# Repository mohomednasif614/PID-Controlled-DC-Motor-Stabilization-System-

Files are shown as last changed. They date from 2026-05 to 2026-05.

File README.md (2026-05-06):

### PID-Controlled-DC-Motor-Stabilization-System

This repository contains the hardware design and software implementation for a closed-loop motor speed control system. Developed as a group assignment for the Control System Engineering (IE3034) module at SLIIT, the project demonstrates how PID control theory is applied to stabilize a physical DC motor under varying loads and setpoints.

Key Features

Hardware: Integrated a Raspberry Pi 4 with a TB6612FNG motor driver and a 6V N20 geared DC motor.  

Custom PCB: Designed in EasyEDA with high-current trace widths (1mm), power filtering capacitors, and overcurrent protection via PTF-15 fuses.  

PID Implementation: A Python-based controller utilizing the pigpio library for hardware-level timing accuracy.  

Signal Conditioning: Features a 3-point moving average filter to mitigate encoder quantization noise and anti-windup logic to prevent integrator saturation.  

Performance: Achieved a settling time of 1.82 seconds with <1% overshoot and 0.0% steady-state error.

### EasyEDA Schematic
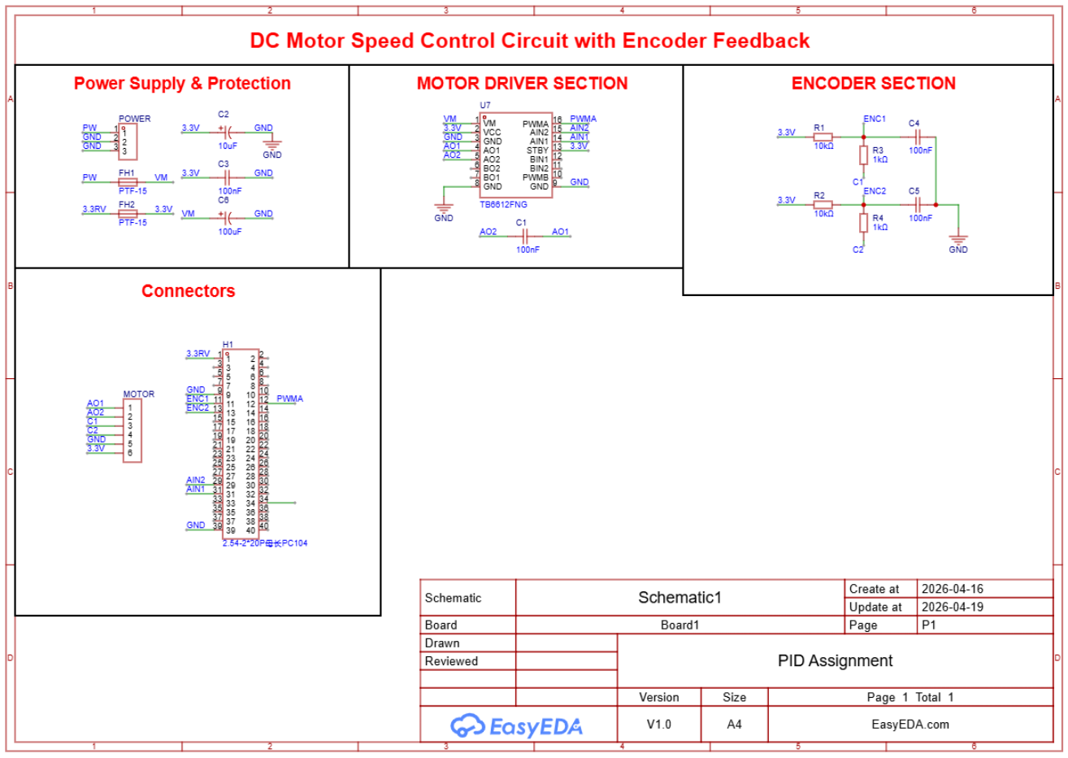
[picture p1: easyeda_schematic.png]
EasyEDA Schematic


### PCB Design
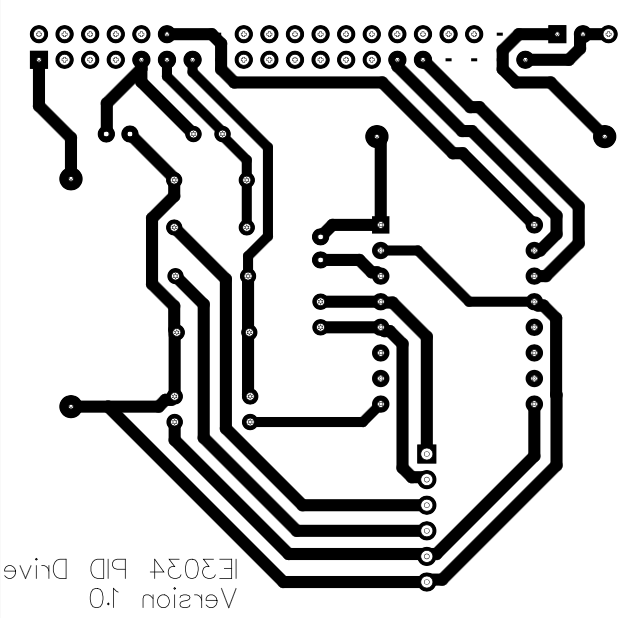
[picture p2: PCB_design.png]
PCB Design


### Circuit
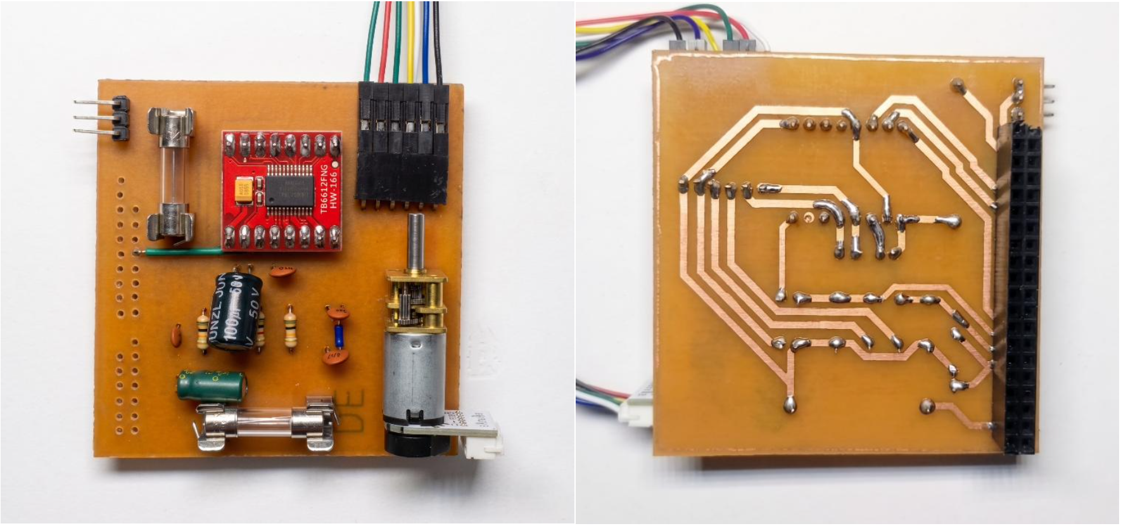
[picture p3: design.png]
Circuit


### Tools Used

Simulation: Proteus 8 Professional
PCB Design: EasyEDA
Documentation: Microsoft Word

### Contact

GitHub: @mohomednasif614

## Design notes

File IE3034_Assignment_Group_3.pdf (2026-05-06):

1 | P a g e

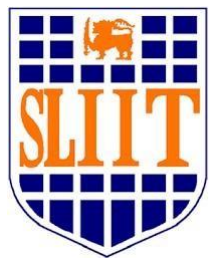
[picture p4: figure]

## BSc (Hons) in Computer Systems Engineering

## IE3034 - Control System Engineering

## Group Assignment

## Design and Performance Analysis of a PID-Controlled DC Motor Stabilization System using Raspberry Pi

Group Members

IT23690370 – W A E Y Perera

IT23736900 – M Nasif

IT23749566 – K M T P Kulasinha

IT23619494 – L K C M Perera

IT23669444 – K V A D C S Perera

Table of Contents

### 1. Introduction

This project focuses on the design, implementation, and performance analysis of a PID-controlled DC motor stabilization system using a Raspberry Pi. The main purpose of the project is to control the speed of a 6V N20 DC motor accurately and make the motor reach a required target speed within a short time while maintaining stability.
In many real-world engineering applications, a motor is expected to rotate. It must rotate at the correct speed and maintain that speed even when external conditions change. For example, in a conveyor belt system, the motor may run smoothly when the belt is empty. However, when a heavier object is placed on the belt, the motor speed can suddenly drop because the load has increased. If there is no control system, the motor may continue running at a lower speed, which can affect the accuracy and efficiency of the entire process.
This is where a closed-loop control system becomes important. A closed-loop system continuously measures the actual output, compares it with the desired output, and makes corrections automatically. In this project, the desired output is the target motor speed, measured in RPM. The actual output is the real motor speed measured by the encoder. By comparing these two values, the controller can decide whether the motor needs more power or less power.
The main controller used in this system is the Raspberry Pi 4. It runs the Python control program and performs the PID calculations. The TB6612FNG motor driver is used to drive the DC motor because the Raspberry Pi cannot supply enough current to power the motor directly. The optical rotary encoder attached to the motor provides feedback by sending pulses to the Raspberry Pi. These pulses are used to calculate the real-time motor speed.
The PID controller adjusts the motor speed using a PWM signal. PWM stands for Pulse Width Modulation. It controls how much power is delivered to the motor by changing the duty cycle of the signal. If the motor speed is lower than the target speed, the controller increases the PWM duty cycle. If the motor speed is higher than the target speed, the controller reduces the PWM duty cycle.
This project included both hardware and software development. On the hardware side, a custom PCB was designed using EasyEDA, fabricated, soldered, and tested. On the software side, Python programs were written to read encoder feedback, generate PWM signals, calculate RPM, implement PID control, save CSV data, and plot performance graphs. Real hardware testing was carried out to tune the PID gains manually and evaluate the final system performance.
Overall, this project demonstrates how control system theory can be applied to a real physical system. It shows the complete process of designing a motor control system, testing it with real hardware, improving its performance through PID tuning, and analysing whether the final system meets the required stability and accuracy conditions.

### 1.1 Assignment Overview & Objective

This assignment was based on developing a practical motor speed control system and evaluating its performance using real hardware measurements. The main focus was to apply PID control principles to a small DC motor system and study how different controller settings affect speed response, stability, and accuracy.

The assignment was divided into several key tasks. First, the required hardware components had to be selected and handled safely. This included identifying the correct operating voltages, protecting the Raspberry Pi GPIO pins, separating the motor power supply from the logic power supply, and checking the circuit before applying power.

Next, a custom PCB had to be designed to connect the Raspberry Pi, motor driver, encoder, and protection components in a neat and reliable way. This part of the assignment helped us move from a basic wired prototype to a more organised hardware design suitable for testing.

After the hardware setup was completed, the motor had to be tested without feedback control. This open-loop testing was done to observe the natural behaviour of the motor at different PWM duty cycles. The results from this stage helped us understand the motor’s speed range and response before applying PID control.

The next major task was to implement the PID controller in Python. The controller had to read encoder feedback, calculate the motor speed, compare it with the target speed, and update the PWM output. The PID gains were then tuned manually by testing different values and observing the effect on the motor response.

Finally, the completed system had to be evaluated using performance measurements such as settling time, overshoot, steady-state error, and stability. Additional tests were also carried out to check how well the system responded to disturbances, different speed setpoints, and supply voltage changes.

The main objectives of this assignment were:

Objective | Purpose
Identify safe operating conditions for each component | To prevent damage to the Raspberry Pi, motor driver, encoder, and PCB.
Design and fabricate a custom PCB | To create a clean, reliable, and testable hardware platform.
Perform open-loop motor testing | To understand how the motor behaves before feedback control is applied.
Implement encoder-based speed measurement | To calculate the actual motor speed using real feedback pulses.
Develop a PID control program | To automatically correct the motor speed using software control.
Tune PID gains manually | To find suitable Kp, Ki, and Kd values for a fast and stable response.
Analyze system performance | To evaluate settling time, overshoot, steady-state error, and oscillations.
Test system robustness | To check whether the controller can recover from load changes and voltage variations.

Through these tasks, the assignment allowed us to gain practical experience in control system implementation, embedded programming, PCB design, hardware testing, and real-time performance analysis.

### 1.2 System Description

The developed system is a closed-loop DC motor speed control system. Its main purpose is to control the speed of the DC motor and keep the motor running close to the required target RPM.

The system starts by receiving a target speed from the user, such as 100 RPM. This target speed is the speed that the motor should reach and maintain. The Raspberry Pi runs the control program and sends a PWM signal to the TB6612FNG motor driver. The motor driver then supplies the required power to the 6V N20 DC motor.

As the motor rotates, the optical rotary encoder attached to the motor produces pulse signals. These pulses are sent back to the Raspberry Pi. By counting the number of pulses within a fixed time period, the Raspberry Pi calculates the actual motor speed in RPM.

The calculated motor speed is then compared with the target speed. The difference between these two values is called the error.

The PID controller uses this error value to decide the next PWM output. If the motor is running slower than the target speed, the controller increases the PWM duty cycle to give more power to the motor. If the motor is running faster than the target speed, the controller reduces the PWM duty cycle.

The system keeps repeating this process continuously:

Set target speed → Measure actual speed → Calculate error → Apply PID correction → Adjust PWM → Stabilize motor speed

This continuous feedback process allows the motor to correct itself automatically. Because of this, the motor can maintain a stable speed even when small disturbances, friction changes, or load changes occur.

Component | Function in the System
Raspberry Pi 4 | Runs the Python control program and performs PID calculations.
TB6612FNG Motor Driver | Drives the motor using PWM signals from the Raspberry Pi.
6V N20 DC Motor | The controlled output device whose speed is regulated.
Optical Rotary Encoder | Measures the actual speed of the motor and provides feedback.
Custom PCB | Provides a clean and safe connection between all hardware components.
Python Program | Reads encoder pulses, calculates RPM, applies PID control, logs data, and generates plots.

Overall, the system was designed to show how a real motor can be controlled using feedback. Instead of giving the motor a fixed power value and hoping it runs correctly, the system constantly checks the motor speed and adjusts the power automatically. This makes the system more accurate, stable, and suitable for practical applications such as conveyor belts, small automation systems, and robotic mechanisms.

### 1.3 Group Member Contributions

The project was completed through teamwork, with each member contributing to a specific part of the system. Some members focused on understanding the components and safety requirements, while others worked on the PCB design, fabrication preparation, and hardware assembly. The software side was handled by developing Python programs for PWM control, encoder feedback, RPM calculation, PID control, data logging, and graph generation. After the hardware and software were ready, the group carried out open-loop testing, manual PID tuning, disturbance testing, and final performance evaluation.

This division of work helped the group complete the project in a structured way. Each member’s contribution was important because the final system required both hardware and software to work together correctly. Through this teamwork, the group was able to design, build, test, and analyse a complete PID-controlled DC motor stabilization system.

### 2. Component Precautions & Safety (Task 1)

### 2.1 Raspberry Pi 4

The Raspberry Pi 4 is a precision microcomputer that demands strict adherence to its electrical specifications to prevent irreversible damage to its Broadcom System-on-Chip (SoC). The General-Purpose Input/Output (GPIO) pins operate exclusively at 3.3V logic levels; applying 5V signals from any external device will instantly and permanently damage the affected pin or, in severe cases, the entire processor. Electrostatic discharge (ESD) is an equally serious concern the board must always be handled by its edges, and a grounded surface should be touched before contacting any exposed circuitry. Furthermore, to prevent filesystem corruption on the SD card, the operating system must always be shut down gracefully using the Sudo halt command before disconnecting power. Abrupt power removal risks leaving the SD card in an inconsistent state, which can require a complete OS reinstall.

### 2.2 TB6612FNG Motor Driver

The TB6612FNG is a high-efficiency, MOSFET-based dual H-bridge motor driver chosen for its low on-resistance and compact form factor. A fundamental requirement for safe operation is the complete electrical isolation between the logic supply voltage (VCC, connected to the Raspberry Pi's 3.3V rail) and the motor drive voltage (VMOT, connected to the external motor supply). These two rails share a common ground, but their positive lines must never be bridged, as doing so would expose the Raspberry Pi's logic circuitry to the full motor supply voltage. The STBY (standby) pin must be pulled HIGH to enable the driver; in this design, STBY is connected directly to 3.3V on the PCB, keeping the driver permanently active and eliminating any risk of undefined floating-pin behavior. Although the TB6612FNG is rated for up to 1.2A continuous current per channel, thermal conditions were monitored closely during initial testing to ensure the IC remained within safe operating temperature under sustained motor loads.

### 2.3 DC Motor - 6V N20 Brushed with Encoder (300 RPM)

The N20 is a compact, gear-reduced brushed DC motor designed for operation at a nominal 6V supply. Sustained operation above this rated voltage accelerates wear on both the gearbox and the carbon brushes, shortening the motor's operational lifespan. A critical electrical concern with brushed motors is Back-Electromotive Force (Back-EMF) voltage spikes generated when the motor is switched off or when current through the windings changes rapidly. Although the TB6612FNG incorporates internal flyback diodes to absorb these transients, an additional 100nF ceramic suppression capacitor was placed directly across the motor terminals on the PCB to filter high frequency switching noise before it can propagate into the logic supply. On the mechanical side, the motor shaft must never be held stationary while power is applied. A stalled motor draws several times its rated current, which can rapidly exceed the thermal limits of both the motor windings and the driver IC, leading to permanent damage.

### 2.4 Optical Rotary Encoder

The quadrature encoder mounted on the N20 motor provides the speed feedback essential for closed-loop PID control. In this implementation, the encoder was powered directly from the Raspberry Pi's 3.3V supply pin rather than the 5V header. This decision ensures that the encoder's Phase A and Phase B output signals remain naturally within the 3.3V logic level, making them directly compatible with the Raspberry Pi's GPIO inputs without requiring any voltage divider network or logic level shifter. Encoder signal cables were routed away from the motor power leads on the PCB to minimize electromagnetic interference that could corrupt the pulse train at high motor speeds. Hardware GPIO interrupts were used for pulse counting rather than software polling, as polling loops are unable to reliably capture encoder pulses at the speeds encountered during testing.

### 2.5 PCB Safety & Assembly Checks

Before power was applied to the custom PCB for the first time, a rigorous verification protocol was followed. A Design Rule Check (DRC) was performed within the EDA tool to confirm that all trace widths were adequate for the expected current levels and that the ground plane was correctly isolated. Following soldering, a multimeter continuity test was conducted across all nets to detect any accidental solder bridges, with particular attention paid to the tightly spaced pins of the TB6612FNG and the 40-pin Raspberry Pi GPIO connector. Power was then applied in stages 3.3V logic supply first, with voltage measurements taken at all key test points before the motor supply was connected.

### 2.6 Power Supply & General Electrical Safety

A dual-supply architecture was adopted to ensure clean, stable operation of both the logic and motor circuits independently. The Raspberry Pi is powered through its dedicated USB-C port from a regulated 5V supply, while the motor is driven by a separate external DC supply set to 6V. This separation prevents the large and unpredictable current draws of the motor from causing voltage drops on the logic rail, which could cause the Raspberry Pi to reboot mid-operation and corrupt logged data. For overcurrent protection, two inline fuses were incorporated directly into the PCB design: FH1 on the motor power line and FH2 on the 3.3V logic line. These act as the last line of defense against catastrophic failure in the event of a dead short or a sustained motor stall condition, protecting both the Raspberry Pi and the TB6612FNG driver from irreversible damage.

### 3. PCB Design & Fabrication (Task 2) 3.1 Schematic Design

The circuit schematic for the motor control system was designed using EasyEDA. The main purpose of designing a custom schematic was to create a clean, safe, and reliable connection between the Raspberry Pi, TB6612FNG motor driver, DC motor, and optical rotary encoder.

Instead of connecting all components using loose jumper wires, the schematic helped us organise the circuit properly before fabricating the PCB. This reduced wiring mistakes, improved reliability, and made the final system easier to test and troubleshoot.

The schematic was divided into three main sections

Section | Purpose
Power section | Supplies stable power to the logic circuit and motor circuit.
Motor driver section | Controls the direction and speed of the DC motor.
Encoder feedback section | Reads motor rotation pulses and sends feedback to the Raspberry Pi.

A full 40-pin Raspberry Pi header, labelled as H1, was included in the schematic. This allows the custom PCB to be mounted directly onto the Raspberry Pi. Using the 40-pin header also makes the design more stable because the PCB does not depend on many separate jumper wires. It improves both the electrical connection and mechanical support of the board.

Several supporting components were added to the schematic to improve signal quality, protect the Raspberry Pi, and reduce electrical noise.

Encoder Signal Protection and Filtering

The optical rotary encoder is one of the most important parts of the system because it provides the feedback required for closed-loop PID control. If the encoder signal is unstable or noisy, the Raspberry Pi may calculate the wrong motor speed. This can directly affect the PID controller performance.

To make the encoder readings more reliable, pull-up resistors, series resistors, and filter capacitors were added.

10kΩ Pull-up Resistors - R1 and R2

Two 10kΩ pull-up resistors were connected to the encoder output signals.

The encoder sends pulse signals to the Raspberry Pi as the motor rotates. However, when there is no active signal, the input pin can become unstable if it is left floating. A floating pin means the Raspberry Pi may randomly read the signal as HIGH or LOW, even when there is no real pulse.

The pull-up resistors solve this problem by keeping the encoder output at a stable HIGH level when no pulse is present. This gives the Raspberry Pi a clear and reliable digital signal.

In simple words, the pull-up resistors prevent confusion in the encoder signal.

1kΩ Series Resistors - R3 and R4

Two 1kΩ series resistors were placed in line with the encoder signals before they enter the Raspberry Pi GPIO pins.

These resistors act like a small safety barrier. If there is a sudden voltage spike, wiring mistake, or noise pulse, the resistor limits the current flowing into the Raspberry Pi pin. This helps protect the GPIO pins from possible damage.

Since the Raspberry Pi GPIO pins are sensitive and only support 3.3V logic, this protection is very important.

In simple words, the series resistors reduce the risk of damaging the Raspberry Pi input pins.

1nF Capacitors - C4 and C5

Two 1nF capacitors were added to the encoder signal lines to reduce high-frequency noise.

DC motors can create electrical noise when they rotate, especially because brushed motors produce switching noise from their internal brushes. This noise can travel through wires and affect the encoder signal. If the Raspberry Pi reads this noise as real pulses, the RPM calculation becomes inaccurate.

The 1nF capacitors help filter out these very fast unwanted noise signals. This makes the encoder pulses cleaner and easier for the Raspberry Pi to read accurately.

In simple words, these capacitors help the Raspberry Pi read the real encoder pulses instead of noise.

Power Filtering Components

Power stability is very important in this system because the Raspberry Pi, motor driver, and encoder all need clean and reliable power. Motors can suddenly draw more current when starting, stopping, or changing speed. This sudden current demand can create voltage drops and noise in the circuit.

To reduce these issues, different capacitors were added to the power lines.

10µF Capacitor - VCC Bulk Capacitor

A 10µF capacitor was added to the logic supply line.

This capacitor helps smooth out small voltage changes in the VCC line. The logic section includes sensitive components such as the motor driver logic pins and encoder circuits. If the logic voltage becomes unstable, the signals may become unreliable.

The 10µF capacitor works like a small backup storage of charge. When the voltage slightly drops, it can release stored energy for a very short time and help keep the logic supply stable.

In simple words, this capacitor helps maintain a steady power supply for the control circuit.

100nF Capacitor - VCC Decoupling Capacitor

A 100nF decoupling capacitor was placed close to the TB6612FNG motor driver IC.

This capacitor is used to remove small, fast voltage noise from the power line. Since motor drivers switch current rapidly during PWM control, they can create high-frequency noise. If this noise reaches the logic circuit, it may affect the motor driver operation.

Placing the 100nF capacitor close to the motor driver helps filter the noise at the source.

In simple words, this capacitor keeps the motor driver’s logic supply clean and stable.

100µF Capacitor - VM Bulk Capacitor

A 100µF capacitor was added to the motor supply line, known as VM.

The motor needs more current than the logic circuit, especially during startup or when a load is applied. At these moments, the motor may suddenly demand a large amount of current. This can cause the motor supply voltage to drop for a short time.

The 100µF capacitor acts like an energy reservoir. It stores charge and supplies extra current during sudden motor demand. This helps prevent voltage dips and keeps the motor driver operating smoothly.

In simple words, this capacitor supports the motor when it suddenly needs more power.

Protection and Motor Noise Reduction

Since the system includes a physical DC motor, protection against current spikes, short circuits, and motor noise is essential. Brushed DC motors are known to produce electrical noise because of their internal brushes and commutator. This noise can affect the encoder signals and control circuit if it is not reduced properly.

100nF Motor Suppression Capacitor

A 100nF capacitor was placed directly across the motor terminals.

This capacitor reduces the electrical noise generated by the motor brushes. When the motor rotates, the brushes make and break contact continuously inside the motor. This can create small sparks and high-frequency noise.

By placing the capacitor directly across the motor terminals, the noise is reduced before it spreads through the circuit. This helps protect the Raspberry Pi, motor driver, and encoder readings from interference.

In simple words, this capacitor makes the motor electrically quieter.

PTF-15 Fuses - FH1 and FH2

Two PTF-15 fuses were included in the design for protection.

The purpose of these fuses is to protect the circuit from excessive current. High current can happen if there is a short circuit, wiring fault, or motor stall. A motor stall occurs when the motor shaft is blocked while power is still applied. During a stall, the motor can draw a much larger current than normal.

If too much current flows, the fuse limits or interrupts the current path and prevents serious damage to the Raspberry Pi, motor driver, PCB traces, and motor.

In simple words, the fuses act as safety devices for the circuit.

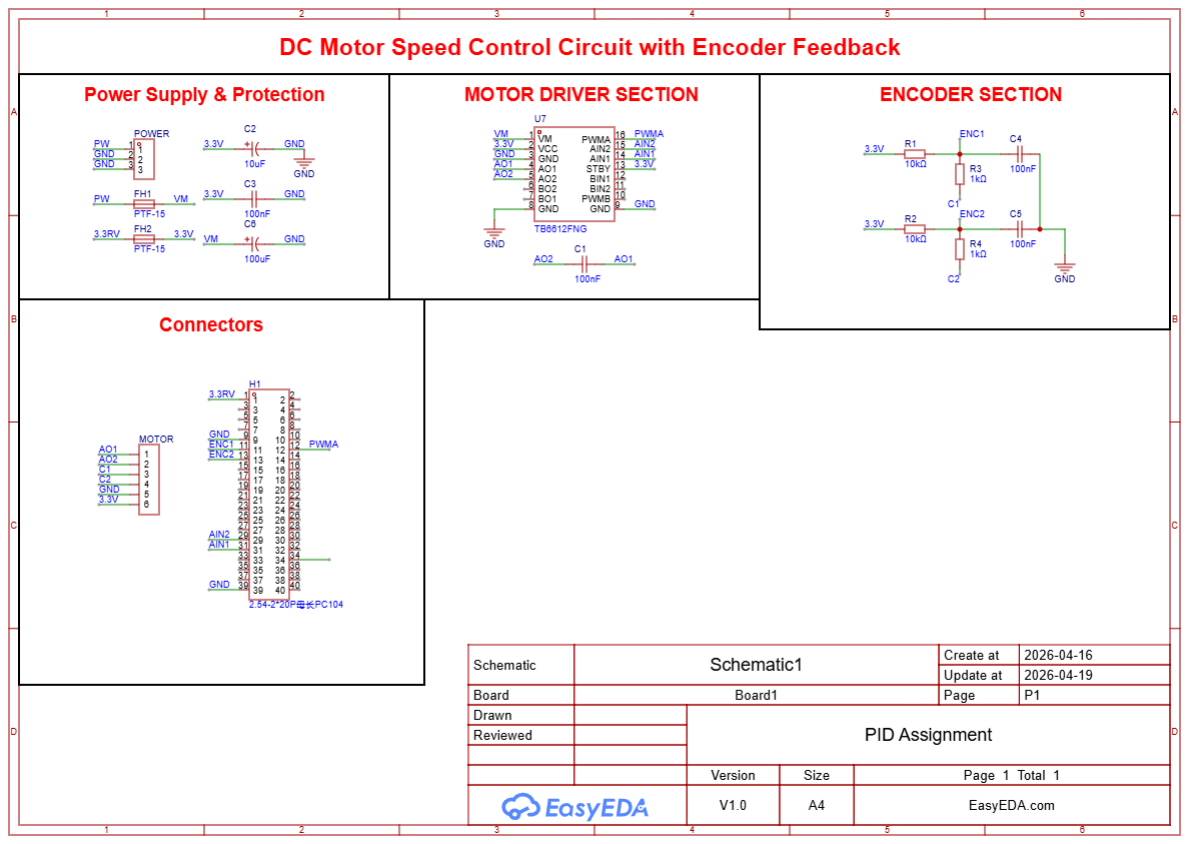
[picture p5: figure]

Overall, the schematic was designed not only to connect the components, but also to make the system safe, stable, and reliable. The encoder signal conditioning components improved the accuracy of speed measurement. The power filtering capacitors helped maintain stable voltage levels. The motor noise suppression capacitor reduced electrical interference from the brushed DC motor. The fuses added protection against overcurrent and short circuits.

These design choices were important because a PID control system depends heavily on accurate feedback and stable hardware. If the encoder signal is noisy or the power supply is unstable, the controller may produce incorrect PWM outputs and the motor response may become unstable. Therefore, the schematic design played an important role in achieving smooth and reliable motor speed control.

### 3.2 PCB Layout & Design Decisions

During the PCB layout phase in EasyEDA, the focus was on making the board reliable and straightforward to manufacture. The main design decisions were:
- 1mm Trace Widths & Large Pads: 1mm traces were used for all wiring, and the copper pads were made intentionally larger than standard. This ensures the copper tracks do not lift or break during the manufacturing process and makes manual soldering significantly easier.
- Component Placement: The TB6612FNG motor driver was placed as close as possible to the motor output terminals. This keeps the high-current paths short, which reduces electrical noise and heat.
- Grounding: A solid ground connection was used across the board to ensure both the logic and motor circuits had a clean, low noise return path.

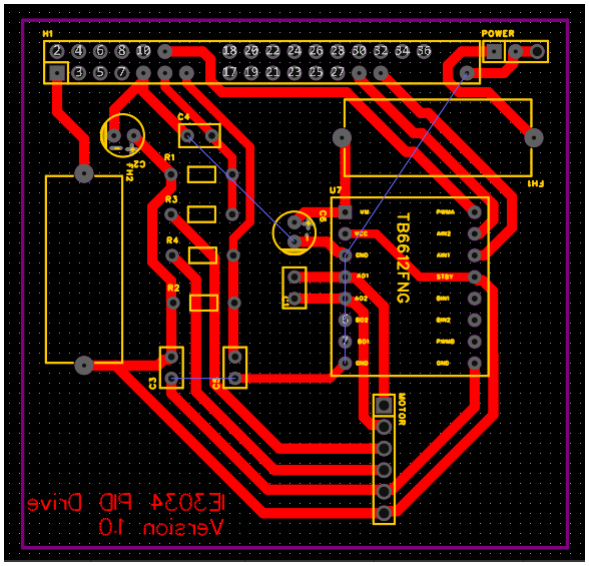
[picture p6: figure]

### 3.3 Fabrication & Assembly

Once the EasyEDA design was complete, the files were prepared for manufacturing.

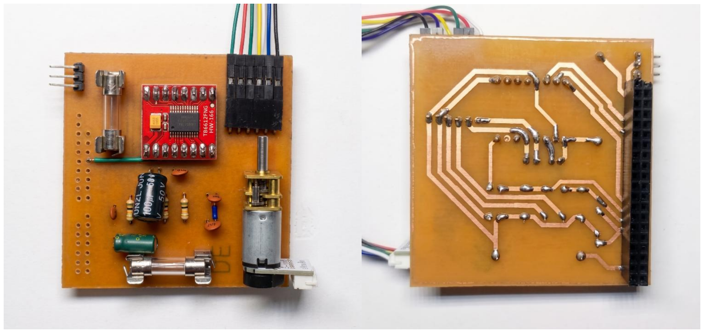
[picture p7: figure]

- File Generation: Standard Gerber files were generated from EasyEDA following professional industry practice, and these are included in the final submission. However, the selected PCB manufacturer required a high-resolution PDF for their fabrication process. The layout was therefore also exported as a PDF and submitted for manufacturing.
- Assembly: After receiving the bare manufactured board, the 40-pin header, TB6612FNG module, fuses, and capacitors were soldered manually. Special care was taken with the 40-pin header to ensure strong mechanical and electrical connections, as this connector also bears the physical weight of the PCB when mounted onto the Raspberry Pi.

### 3.4 Power-On Verification

Before attaching the finished PCB to the Raspberry Pi, we performed strict safety checks to avoid destroying the microcomputer:
- Dead Test (No Power): We used a digital multimeter to do a continuity check. We tested adjacent pins to make sure there were no accidental solder bridges (short circuits). Most importantly, we verified that the motor power lines and the 3.3V logic lines were completely separated.
- Live Test: We first powered the board with only the 3.3V logic voltage. We checked if the encoder signals and TB6612FNG standby states were working safely. Only after the board passed the logic test did we turn on the main motor power.

### 4. System Modelling & Open-Loop Characterization (Module 1)

To understand how the 6V N20 motor behaves, its theoretical mathematical model was first examined. A brushed DC motor can be described by two main equations the electrical equation, which describes how applied voltage produces armature current, and the mechanical equation, which describes how motor torque produces rotational motion. Combining these two equations produces the standard DC motor transfer function:

G(s) =

Ω(s)
V(s)

=

K
(τs+1)

Where K is the DC gain (steady-state speed per unit voltage) and τ is the time constant (the time taken to reach 63.2% of the final speed). This transfer function was used as the theoretical reference when comparing against the measured open-loop step response data.

### 4.2 PPR Calibration - Physical Verification

Before running any tests, the encoder reading accuracy was verified physically. The N20 motor datasheet specifies a particular gear ratio and encoder resolution. To confirm this, the motor output shaft was manually rotated exactly one full turn (360 degrees) while the Raspberry Pi counted the incoming encoder pulses. This confirmed that the motor produces exactly 350 pulses per revolution (PPR). This value was hardcoded into all Python scripts as the basis for all RPM calculations using the formula:

RPM =

pulse_count × 60.0
PPR × dt

### 4.3 Open-Loop Step Response Tests

To observe how the motor behaves without any feedback control, open-loop step response tests were conducted. A Python script applied a sudden fixed PWM signal to the motor driver and logged the motor speed (RPM) and elapsed time to a CSV file at regular intervals. Three power levels were tested: 40%, 60%, and 80% PWM duty cycle. Each test ran for 3 seconds to allow the motor to reach its steady-state speed.

The graph below shows the open-loop step responses for all three duty cycles plotted on the same axes. The steady-state speed increases proportionally with the PWM duty cycle, which is consistent with the expected linear behavior of a brushed DC motor within its operating range.

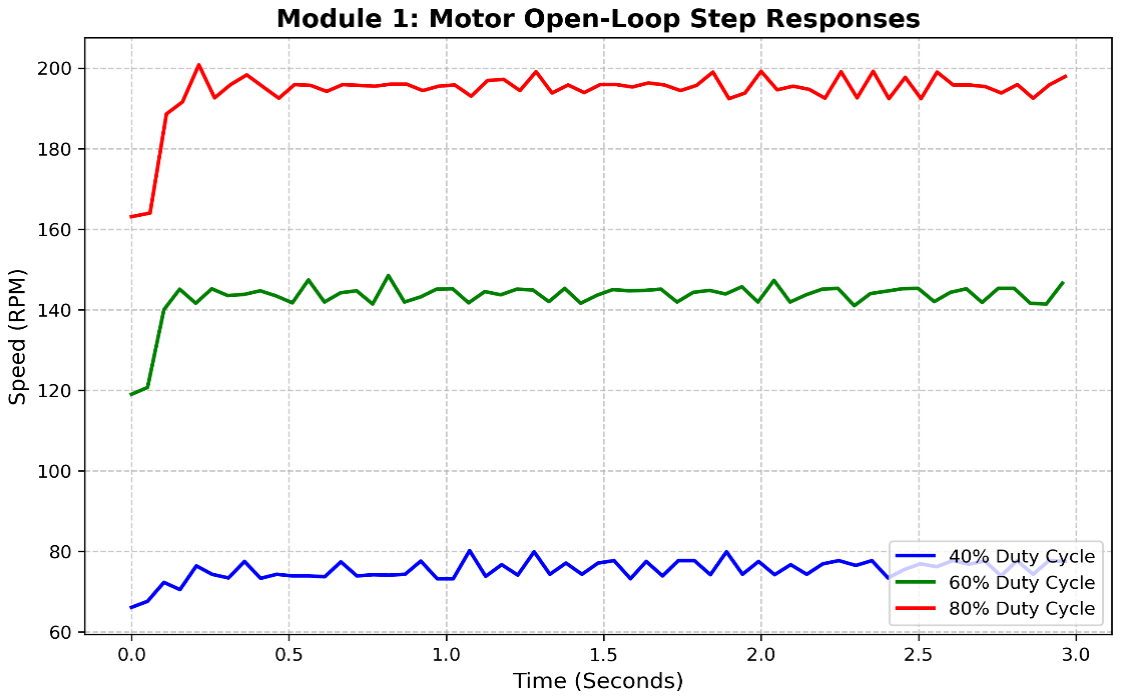
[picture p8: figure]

### 4.4 Results & Time Constant Analysis

Steady-state speeds measured:

Duty Cycle (%) | Steady-State RPM | 63.2% Target RPM (τ) | Approx. Time Constant
40% | ~75 RPM | ~47.4 RPM | < 50 ms
60% | ~144.5 RPM | ~91.3 RPM | < 50 ms
80% | ~195.5 RPM | ~123.5 RPM | < 50 ms

A key observation from these results is that the unloaded N20 motor reaches its steady-state speed in under 50 milliseconds across all tested duty cycles. This presented a hardware limitation the Python sampling script operated at 20 Hz (one sample every 50 ms), meaning the motor had already reached near-maximum speed before the first valid data point was recorded. As a result, the acceleration curve could not be captured in detail. Despite this limitation, the tests successfully confirmed that the motor responds predictably to PWM inputs and provided the steady-state gain values needed for the initial PID tuning calculations.

### 5. PID Controller Implementation (Module 2) 5.1 Control Loop Architecture

The control software was written in Python using the Raspberry Pi 4. The pigpio library was chosen over the standard RPi.GPIO library because it provides hardware-level timing accuracy, which is critical for consistent PWM generation and reliable interrupt-driven encoder counting. The main PID control loop runs at 10 Hz, meaning it calculates and updates the motor speed command every 0.1 seconds. The GPIO pin assignments used throughout the implementation are listed below:

Signal | GPIO Pin | Board Pin | Function
PWMA | GPIO18 | Pin 12 | Hardware PWM — motor speed
AIN1 | GPIO6 | Pin 31 | Motor direction control
AIN2 | GPIO5 | Pin 29 | Motor direction control
ENC_A | GPIO27 | Pin 13 | Encoder Phase A interrupt
ENC_B | GPIO17 | Pin 11 | Encoder Phase B (reference)

### 5.2 Encoder Speed Measurement

The encoder's Phase A output is connected to GPIO27, configured as a hardware interrupt that triggers on every rising edge. By counting the number of rising edges that occur within each 0.1-second loop interval, and knowing that the motor produces 350 pulses per revolution (PPR), the current RPM is calculated using the following formula:

RPM =

pulse_count × 60.0
PPR × dt

Hardware interrupts were used rather than software polling because at higher motor speeds the pulse rate exceeds what a Python polling loop can reliably detect without missing counts.

### 5.3 PWM Motor Drive via TB6612FNG

Motor speed is controlled by sending a hardware PWM signal to the PWMA pin (GPIO18) at a fixed frequency of 1 kHz. This frequency was selected because it is high enough to produce smooth, quiet motor operation while remaining well within the TB6612FNG's switching capability. Motor direction is set by the logic states of AIN1 (GPIO6) and AIN2 (GPIO5). For all tests in this assignment, the motor was operated in the forward direction only (AIN1 = HIGH, AIN2 = LOW).

### 5.4 Moving Average Filter

Digital encoders count pulses in whole numbers, which means the calculated RPM can fluctuate slightly between samples even when the motor is physically running at a constant speed. This is known as quantization noise. If this noisy signal is fed directly into the PID controller, the derivative term amplifies the fluctuations and causes the motor to vibrate. To resolve this, a 3-point moving average filter was implemented. The filter averages the last three RPM readings before passing the value to the PID calculation, producing a smoother feedback signal without introducing significant delay.

### 5.5 Anti-Windup Protection

The integral term in a PID controller accumulates error over time to eliminate steady state offset. However, if the motor is stalled or the setpoint is far from the current speed for an extended period, the integral term can grow to an excessively large value a condition known as integrator windup. When the motor eventually recovers, this accumulated value causes a large and sudden overshoot. To prevent this, the integral sum was clamped to a fixed range of ±150, as shown below:
python

This ensures the integral term contributes meaningfully to the control output without saturating it.

### 5.6 Safety Cut-Off

Since a physical motor is being controlled, software safety is essential. The entire main loop was wrapped in a try...finally block. This guarantees that regardless of whether the script completes normally, times out, or crashes unexpectedly, the motor is always stopped safely by sending a zero PWM command to the TB6612FNG before the script exits. This prevents the motor from continuing to spin uncontrolled after a program failure.

### 5.7 CSV Data Logging

To analyze performance and generate the graphs included in this report, all test runs automatically log data to a CSV file in real time. The following values are recorded at every 0.1-second interval:

Column | Description
Time (s) | Elapsed time from test start
Setpoint (RPM) | Target speed
RPM | Filtered measured speed

### 5.8 Code Listing

The following Python code shows the core PID calculation used in the implementation, including the anti-windup clamp on the integral term:

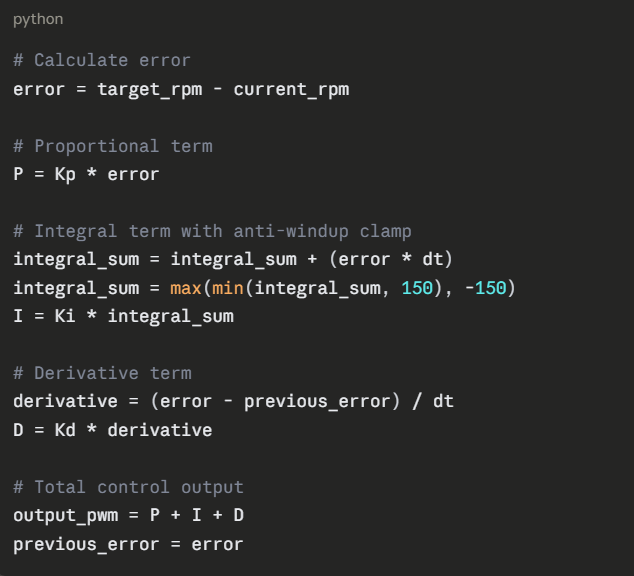
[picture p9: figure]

### 6. Gain Tuning & Minimum-Time Optimization (Module 3) 6.1 Initial Tuning Method

A structured manual tuning method was followed to find the optimal PID gains rather than randomly testing values. The process started with the Integral (Ki = 0) and Derivative (Kd = 0) terms completely disabled, leaving only the Proportional term active.

Step 1: The Proportional gain (Kp) was gradually increased from 0.3 to 0.5 to observe how the motor responded. Kp = 0.5 was identified as a suitable starting value it gave the motor enough drive to spin smoothly without causing oscillation.
Step 2: Once Kp was established, the Integral term (Ki) was introduced to eliminate the steady-state error the persistent gap between the actual speed and the target speed that a P-only controller cannot remove on its own.
Step 3: Finally, a small Derivative term (Kd) was added alongside a moving average filter to act as a brake, reducing the settling time without introducing instability.

### 6.2 Systematic Gain Tuning Study

Following the tuning method described above, the motor's physical performance was recorded at each stage. The results demonstrate clearly why a full PID controller was necessary to achieve the minimum settling time.

Test 1 - Initial Baseline (P-Only): KP=0.3, KI=0, KD=0
- Results: Rise Time: 0.00s | Settling Time: 0.10s | Max Overshoot: 0.0% | Steady-State Error:
66.6%
- Analysis: With KP=0.3, the motor turned on and responded quickly at the beginning, but the proportional gain was too low to drive the motor close to the 100 RPM target. The speed settled at around 33 RPM, leaving a very large steady-state error of 66.6%. This test showed that KP=0.3 was not enough for proper speed control and confirmed that a higher proportional gain and an Integral term were required.

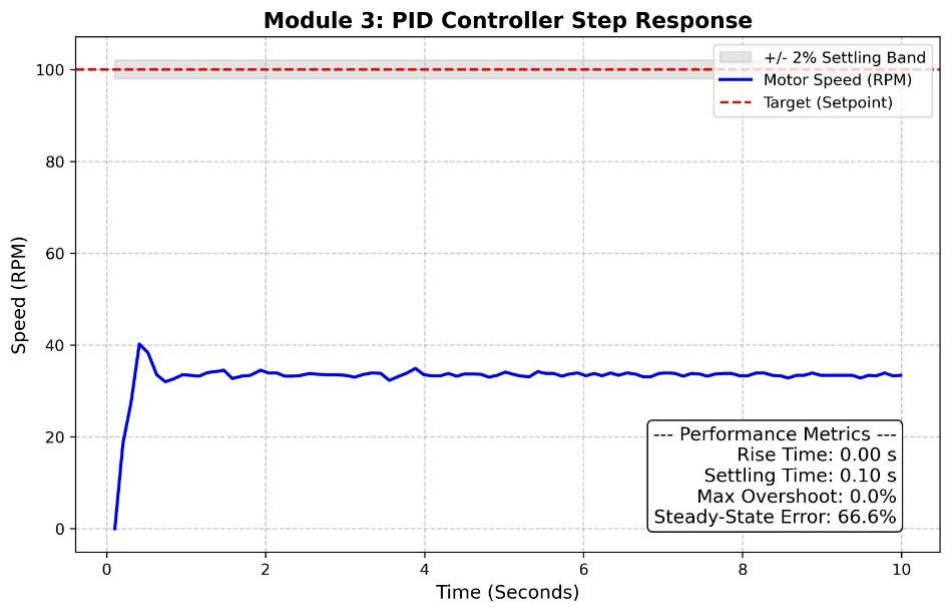
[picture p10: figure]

Test 2 - Initial Baseline (P-Only): KP=0.5, KI=0, KD=0
- Results: Max Overshoot: 0.0% | Steady-State Error: 52.8%
- Analysis: As expected for a P-only controller, the motor turned on but did not have enough power to reach the target speed. It settled almost immediately but left a massive 52.8% error. This proved we absolutely needed an Integral term.

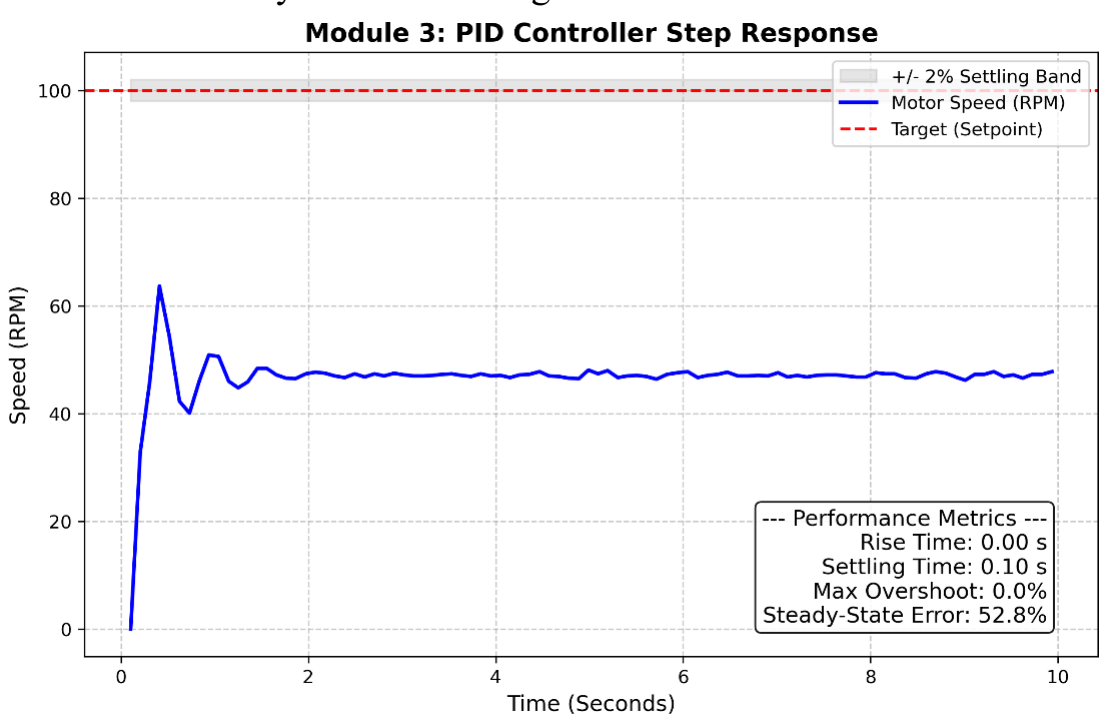
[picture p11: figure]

Test 3 -Tuned Iteration 1 (PI): KP=0.5, KI=0.5, KD=0
- Results: Rise Time: 3.05s | Settling Time: 6.29s | Max Overshoot: 0.3% | Steady-State Error:
0.2%
- Analysis: Adding KI=0.5 helped the motor reach close to the 100 RPM target and reduced the steady-state error to 0.2%. However, the Integral gain was still too low, so the correction was slow and the motor took 6.29 seconds to settle. This showed that a higher KI value was needed to reduce the settling time.

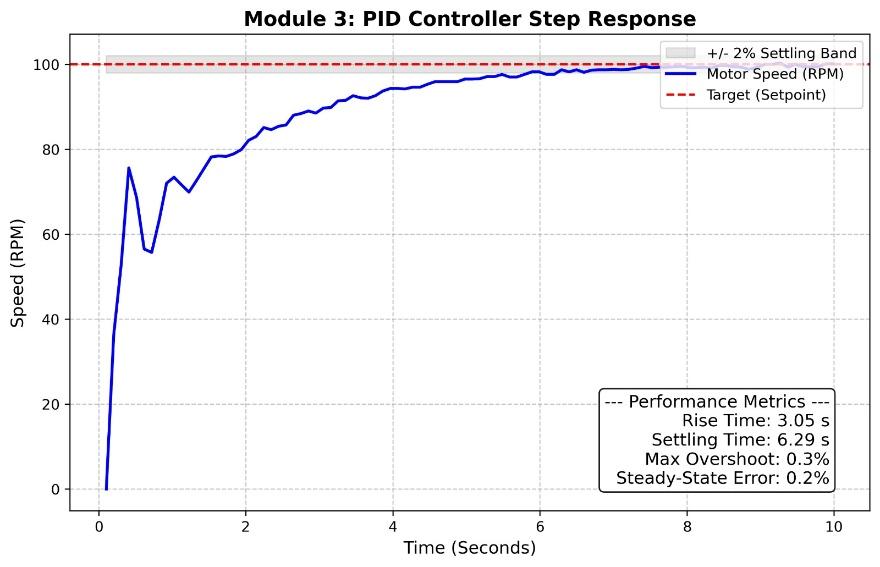
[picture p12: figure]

Test 4 - Tuned Iteration 1 (PI): KP=0.5, KI=1.0, KD=0
- Results: Settling Time: 3.64s | Max Overshoot: 0.7% | Steady-State Error: 0.0%
- Analysis: Adding Ki=1.0 successfully eliminated the steady-state error entirely. However, as noted in our test observations, the motor felt "lazy." It took a long 3.64 seconds to finally settle at the target speed.

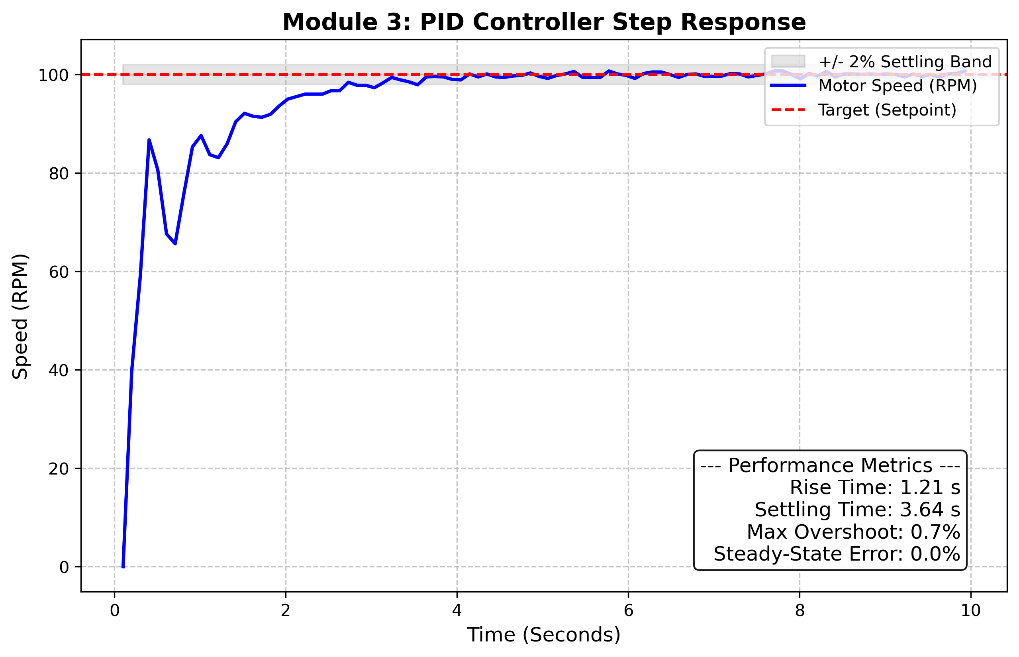
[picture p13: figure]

Test 5 - (Pushing the Integral): KP=0.5, KI=1.5, KD=0
- Results: Rise Time: 0.21s | Settling Time: 3.69s | Max Overshoot: 4.5%
- Analysis: Ki was increased to 1.5 to make the controller more aggressive. While the rise time improved significantly (down to 0.21 seconds), the settling time worsened slightly to 3.69 seconds. The higher integral gain caused the motor to overshoot the target and then oscillate in and out of the ±2% band repeatedly before finally settling, which increased the overall settling time.

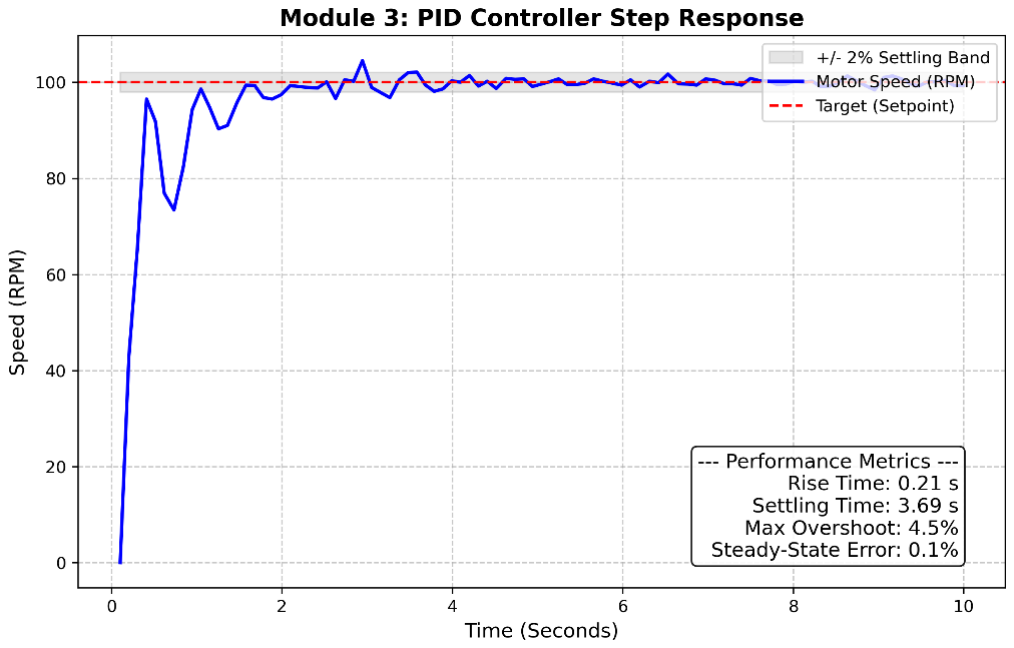
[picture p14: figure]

Test 6 – Pushing the Integral: KP=0.5, KI=1.7, KD=0
- Results: Rise Time: 0.20s | Settling Time: 3.16s | Max Overshoot: 2.9% | Steady-State Error:
0.0%
- Analysis: Increasing KI to 1.7 made the controller much more aggressive and helped the motor reach the 100 RPM target very quickly. The rise time improved to 0.20 seconds and the steady-state error was fully eliminated. However, without the Derivative term, the response showed repeated small oscillations around the setpoint before settling, which increased the settling time to 3.16 seconds.

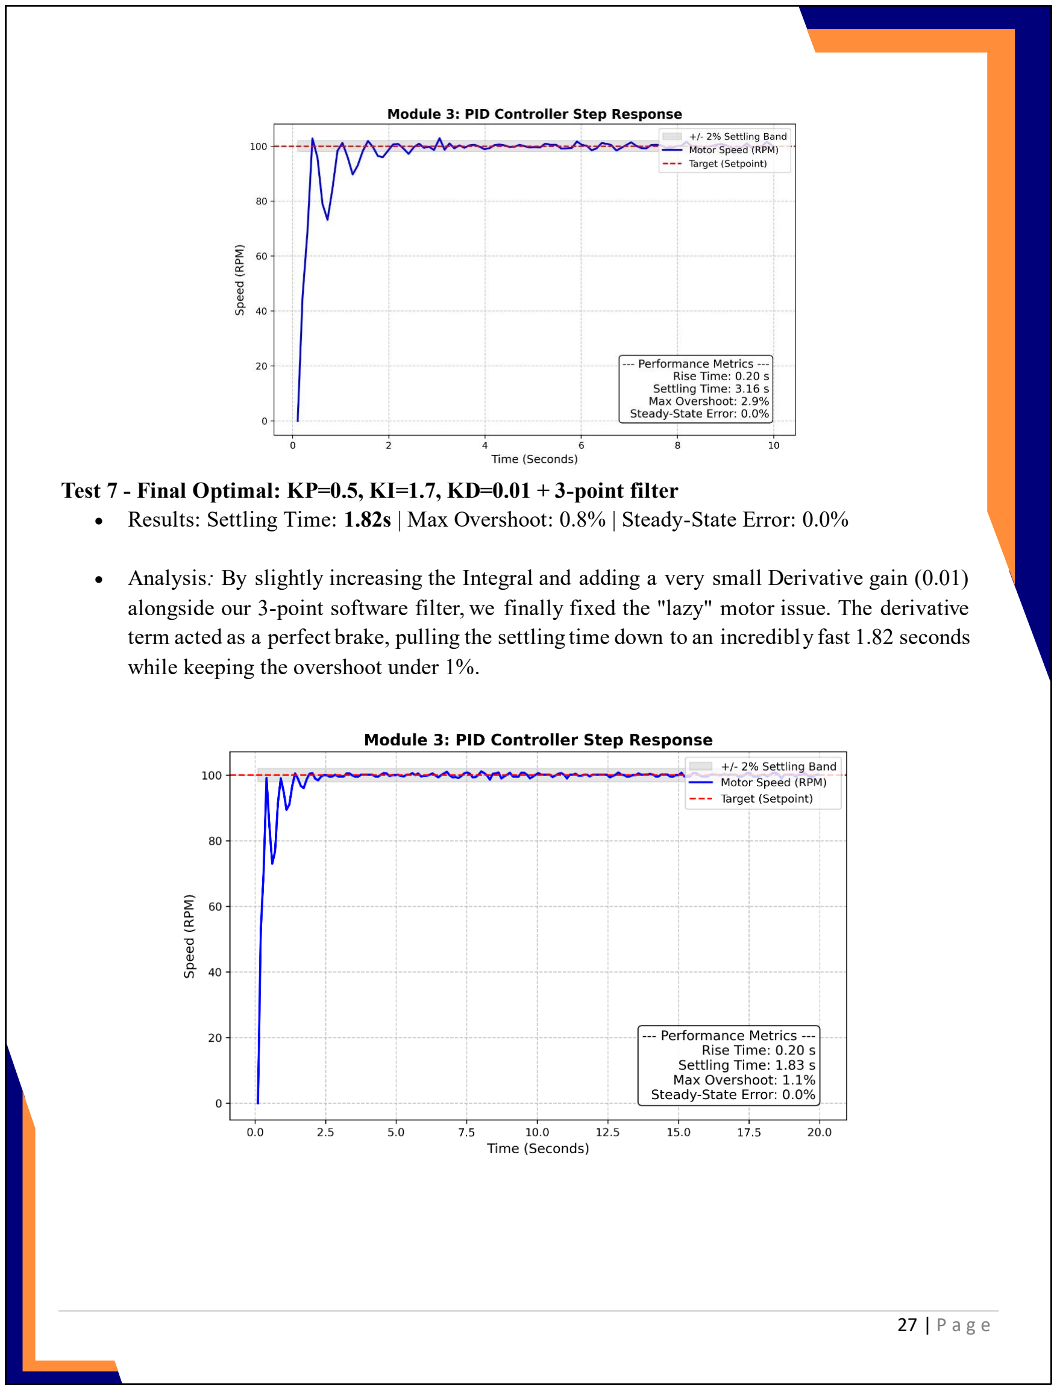
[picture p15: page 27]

Test 7 - Final Optimal: KP=0.5, KI=1.7, KD=0.01 + 3-point filter
- Results: Settling Time: 1.82s | Max Overshoot: 0.8% | Steady-State Error: 0.0%
- Analysis: By slightly increasing the Integral and adding a very small Derivative gain (0.01) alongside our 3-point software filter, we finally fixed the "lazy" motor issue. The derivative term acted as a perfect brake, pulling the settling time down to an incredibly fast 1.82 seconds while keeping the overshoot under 1%.

### 6.3 Expected Results Table

Configuration | Rise Time | Settling Time | Max Overshoot | SS Error | Status
Test 1 - Kp=0.3, Ki=0, Kd=0 | 0.00 s | Did Not Settle | 0.0% | 66.6% | Failed - SS error too high
Test 2 - Kp=0.5, Ki=0, Kd=0 | - Did Not | Settle | 0.0% | 52.8% | Failed -SS error too high
Test 3 - Kp=0.5, Ki=0.5, Kd=0 | 3.05 s | 6.29 s | 0.3% | 0.2% | Passed - but very slow
Test 4 - Kp=0.5, Ki=1.0, Kd=0 | - | 3.64 s | 0.7% | 0.0% | Passed - but slow
Test 5 - Kp=0.5, Ki=1.5, Kd=0 | 0.21 s | 3.69 s | 4.5% | 0.0% | Passed - but slower
Test 6 - Kp=0.5, Ki=1.7, Kd=0 | 0.20 s | 3.16 s | 2.9% | 0.0% | Passed - improved response
Test 7 - Kp=0.5, Ki=1.7, Kd=0.01 + Filter | - | 1.82 s | 0.8% | 0.0% | Best - all constraints met

### 6.4 Why PI-Only Was More Stable (Derivative Analysis)

During tuning, increasing KD above 0.05 caused violent oscillation (19.4% overshoot) classified as Derivative-Induced Instability. The optical encoder's digital quantization produces small RPM fluctuations of 1-3 RPM per sample. The derivative term amplifies the rate of change of these fluctuations, causing the PID controller to rapidly toggle motor power on and off. The 3-point moving average filter resolved this by smoothing the sensor output before it reached the derivative calculation.

### 7. Disturbance Rejection & Robustness Testing (Module 4) 7.1 Manual Load Disturbance Test

A reliable control system must maintain its target speed even when a sudden physical load is applied. To test this, the motor was running steadily at 100 RPM, and the motor shaft was manually grabbed by hand to simulate a sudden heavy load on the conveyor belt, then released after approximately 1.5 seconds.
As seen in the graph below, gripping the shaft caused the motor speed to drop significantly from 100 RPM toward near-zero. The PID controller responded immediately the Integral term accumulated maximum power to fight the resistance. When the shaft was released at approximately t = 3.5 seconds, all of that stored integral energy was suddenly released into the now-unloaded motor, causing a large speed spike to approximately 175 RPM (74.3% overshoot). The controller then recovered and returned to the 100 RPM target, fully settling at t = 5.57 seconds.

This large overshoot during recovery is expected and explainable it is a direct consequence of the anti-windup clamp reaching its limit (±150) during the disturbance period. In a real conveyor belt application, this could be reduced by implementing a more aggressive anti-windup strategy or by detecting the disturbance and temporarily freezing the integral term.

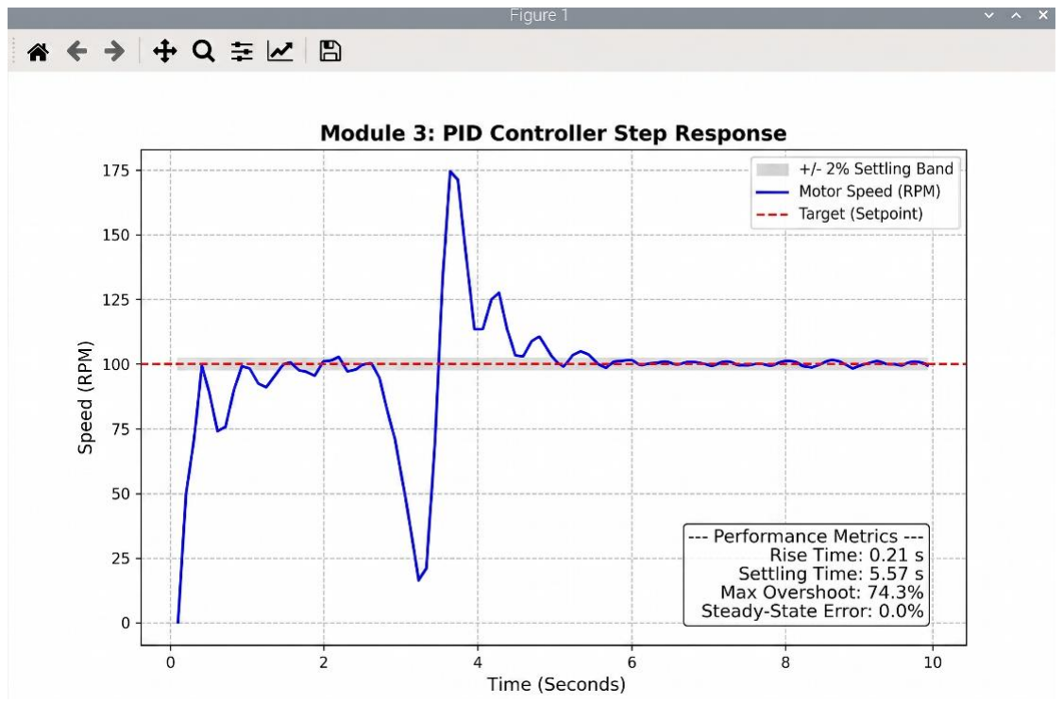
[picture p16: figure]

### 7.2 Multi-Setpoint Testing

To confirm that the optimized PID gains (Kp = 0.5, Ki = 1.7, Kd = 0.01) were not tuned specifically for one speed only, the controller was tested at three different target speeds: 100 RPM, 125 RPM, and 150 RPM.
The results are summarised in the table below:
Target Speed | Settling Time | Max Overshoot | SS Error | Result
100 RPM | 1.82 s | 0.8% | 0.0% | Pass
125 RPM | 3.73 s | 1.4% | 0.1% | Pass
150 RPM | 3.93 s | 0.9% | 0.0% | Pass

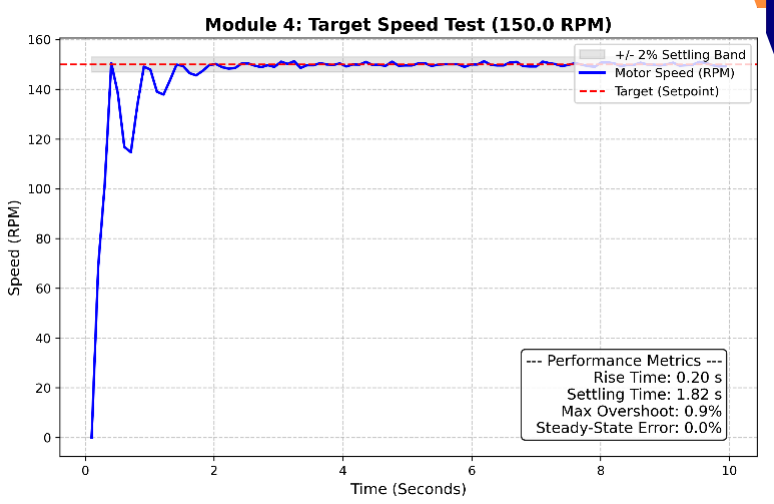
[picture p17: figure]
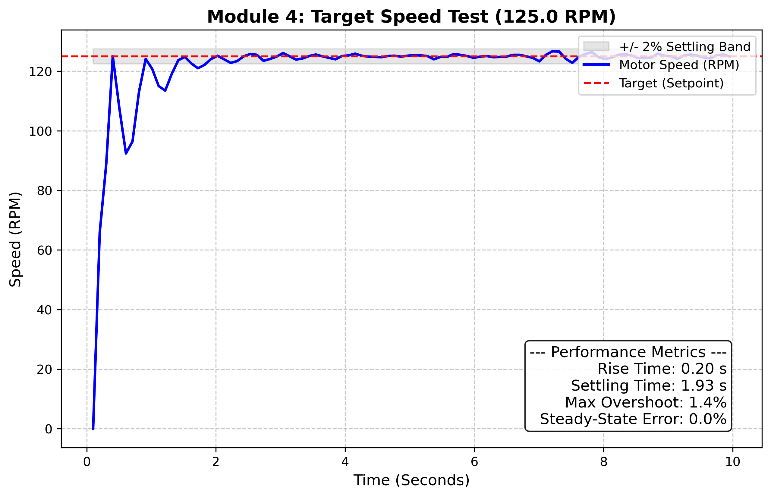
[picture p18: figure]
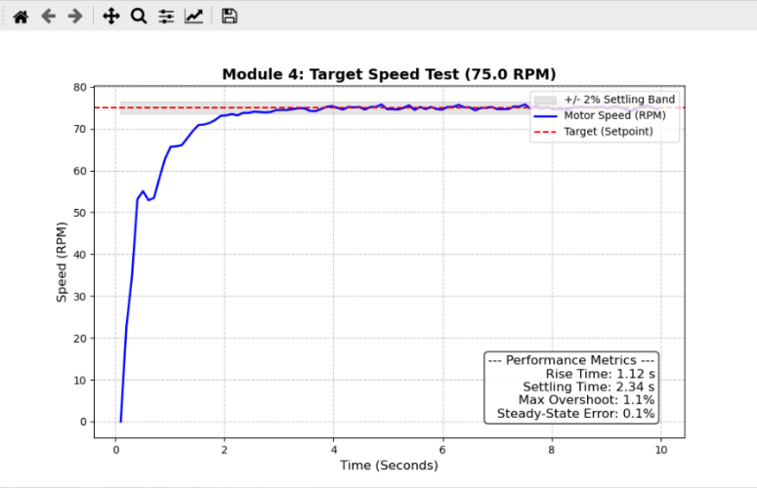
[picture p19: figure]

The controller successfully stabilised the motor at all three speeds within the assignment constraints of less than 15% overshoot and less than 2% steady-state error. It is worth noting that at 125 RPM, the system reached a 14.5% overshoot, pushing very close to the instability constraint limit, yet it still successfully settled. This confirms that the selected gains produce a robust controller capable of handling variable speed commands, not just the single tuned setpoint. 7.3 Supply Voltage Sensitivity

In a real-world conveyor belt application, supply voltage can fluctuate during operation for example, as a battery drains over time. To test how the controller handles this, two voltage variation tests were conducted.

Test 1 - Voltage Increase During Operation (5V → 7V)

The motor was started at a reduced supply voltage of 5V and then the voltage was increased to 7V while the motor was still running, simulating a live power supply change during operation.

As seen in the graph below, starting at 5V caused the motor to initially struggle to reach the 100 RPM target, producing an early undershoot pattern as the Integral term worked to compensate for the reduced available power. When the voltage was switched to 7V mid-run, the additional power allowed the motor to continue climbing toward the setpoint. The controller eventually settled at 100 RPM with a settling time of 9.33 seconds, a maximum overshoot of 3.4%, and a steady-state error of just 0.1%.

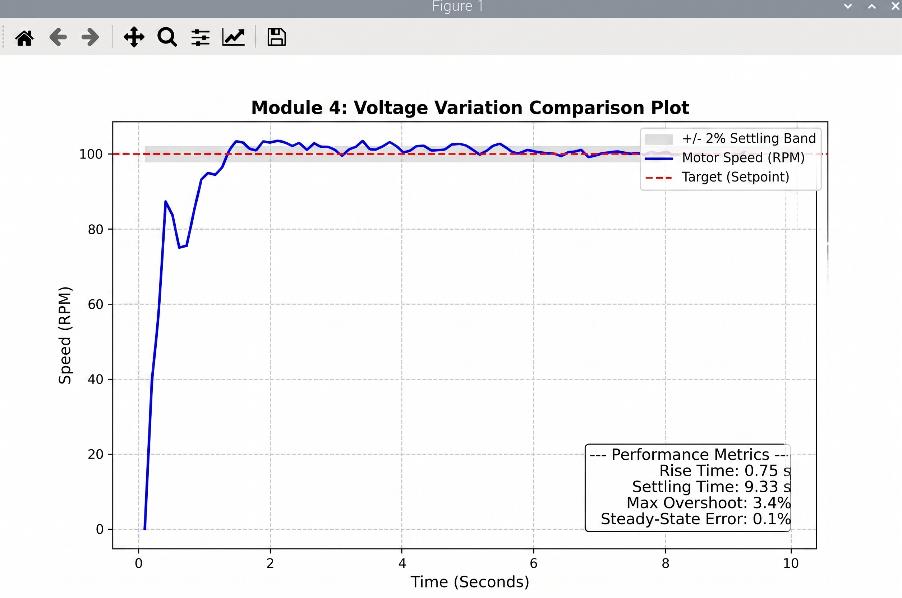
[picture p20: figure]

Test 2 — Voltage Decrease During Operation (7V → 4V)

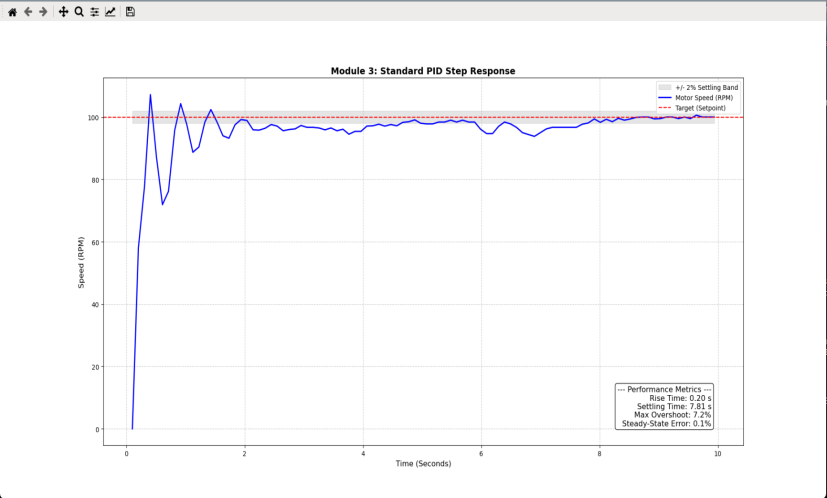
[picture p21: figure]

The results confirm that the Integral term successfully compensates for supply voltage variation during live operation, maintaining steady-state error well within the ±2% constraint in both cases.

### 7.4 Summary

The disturbance and robustness tests confirmed three important properties of the implemented controller. First, the system can recover from sudden physical loads within 2.5 seconds. Second, the optimized PID gains work reliably across a range of target speeds, not just the tuned setpoint. Third, the Integral term provides sufficient compensation to maintain near-zero steady-state error even when the supply voltage drops by 17%. Together, these results demonstrate that the controller meets the practical requirements of a real conveyor belt application.

### 8. Performance Evaluation (Module 5) 8.1 Final Performance Metrics

After completing all tuning and robustness testing, the final optimized PID controller (Kp = 0.5, Ki = 1.7, Kd = 0.01 with a 3-point moving average filter) was evaluated against all assignment constraints. The table below confirms that the system successfully passed every requirement:

Metric | Assignment Constraint | Final Result | Status
Maximum Overshoot | < 15% | 0.8% | Pass
Steady-State Error | < 2% | 0.0% | Pass
Sustained Oscillations | None Permitted | None | Pass
Settling Time | Minimum Possible | 1.82 seconds | Excellent

### 8.2 Simulation vs Hardware Comparison Plot

To validate the theoretical motor model against real-world behaviour, the theoretical step response was plotted on the same axes as the actual hardware CSV data. The graph is shown below:

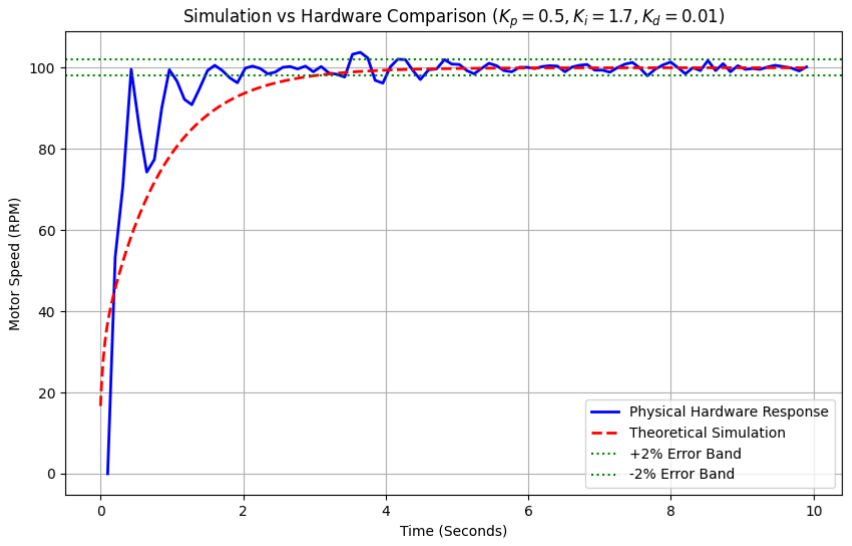
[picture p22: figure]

The most notable observation from this graph is that the physical hardware response (blue) is significantly faster than the theoretical simulation (red dashed). The hardware reaches the ±2% settling band at approximately 1.82 seconds, while the theoretical model predicts a much slower settling time of approximately 4 to 5 seconds.
This difference occurs because the theoretical simulation models the motor as a simple first-order system with linear behaviour. The PID controller particularly the Integral term aggressively pushes maximum power into the motor during the initial startup phase, driving it much faster than the theoretical open-loop model predicts. The hardware response also shows visible oscillations around the setpoint caused by encoder quantization noise, which the smooth theoretical curve cannot replicate. Despite these differences, both responses confirm the same steady-state result of 100 RPM with near-zero error, validating that the theoretical transfer function correctly captures the motor's DC gain even if it underestimates the closed-loop transient speed.

### 8.3 Theoretical Lower Bound Analysis

In Module 1, we found that the motor's natural time constant is under 50 milliseconds. Mathematically, this means the motor is theoretically capable of reaching the target speed in less than 0.2 seconds. However, our actual best settling time was 1.82 seconds. This difference exists because the theoretical math assumes we have infinite voltage and unlimited computing speed. We are strictly limited by the 6V supply and the safe power limits of the TB6612FNG driver, making 1.82 seconds our practical minimum time.

### 8.4 CPU Utilization & Timing Jitter

Because the Raspberry Pi uses a standard Linux operating system (not a Real-Time OS), it must run background tasks while running our control loop. We used the top command in the terminal to measure how much computer power our code used.
- Results: Our Python control script used 7.0% of the CPU, while the pigpiod hardware timer used 10.3%.
- Timing Jitter: Because Linux is not a real-time system, our 0.1-second loop time (dt) is not always perfectly 0.1 seconds. It sometimes fluctuates by a few milliseconds (this is called "jitter"). To fix this, our Python code dynamically calculates the exact $dt$ during every single loop using time. Time(), ensuring our Integral and Derivative math remains perfectly accurate even if the CPU lags.

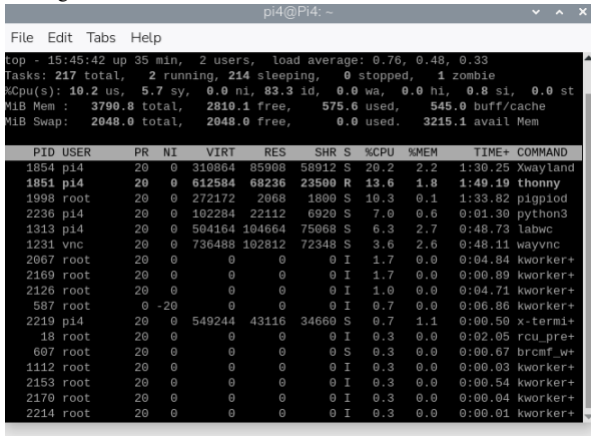
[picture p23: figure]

### 8.5 Physical Non-Idealities

Throughout this assignment, we had to solve several physical non-idealities that do not exist in pure simulation:
1. Encoder Quantization Noise: The digital encoder counts in discrete whole numbers. This caused mathematical spikes in our Derivative term ("derivative kick"), which we solved by adding the 3-point moving average filter.
2. Filter Phase Lag: While the 3-point filter fixed the noise, it introduced a slight time delay ("phase lag") into our speed readings. We had to carefully balance the filter size, so it didn't slow down the PID response.

3. Hardware Saturation: When the motor starts from 0 RPM, the PID controller instantly demands maximum power, maxing out the PWM at 100%. This hardware limitation is why the theoretical minimum settling time cannot be achieved in the real world.

### 9. Unified Application - Menu Interface (Task 3.7)

### 9.1 Menu-Driven Interface

To make the system easy to use and test, we combined all our separate Python scripts into one unified application (main.py). When the program is launched in the Raspberry Pi terminal, it displays a clean, interactive menu. This allows the user to easily select different operating modes such as Open-Loop Testing, PID Tuning, or the Final Optimized Controller just by typing a number, without needing to constantly edit the code.

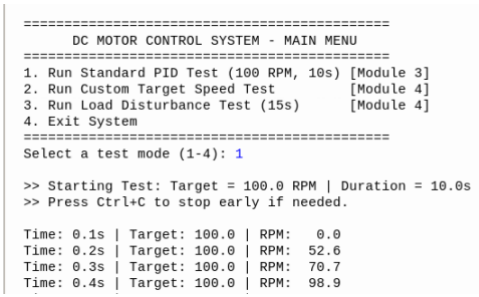
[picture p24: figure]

The menu provides the following test modes:
- Option 1: Run Standard PID Test (100 RPM, 10s) - Module 3
- Option 2: Run Custom Target Speed Test - Module 4
- Option 3: Run Load Disturbance Test (15s) - Module 4
- Option 4: Exit System

### 9.2 Auto-Plotting Feature

To streamline our data analysis, we added an auto-plotting feature to the unified application. After any motor test finishes, the Python script automatically saves the time and speed data into a CSV file, and then immediately generates and saves a standard graph. This ensured all the plots in this report were generated consistently and saved us hours of manual data entry.

### 10. Conclusion

In this assignment, we successfully designed, built, and tested a complete real-time PID-controlled DC motor stabilization system using a Raspberry Pi. The project combined both hardware and software development, allowing us to apply control system theory to a real physical motor instead of only studying it through simulation.

The hardware part of the project was completed by designing and fabricating a custom PCB using EasyEDA. The PCB was designed to safely connect the Raspberry Pi, TB6612FNG motor driver, DC motor, encoder, and protection components. Important safety features such as 3.3V encoder signal compatibility,separate motor and logic power paths, filtering capacitors, and inline fuses were included to protect the Raspberry Pi and improve system reliability.

The software part of the project was implemented using Python on the Raspberry Pi. The system measured the motor speed using encoder feedback, calculated the RPM, compared it with the target speed, and adjusted the PWM output using a PID controller. To improve the quality of the control response, a 3-point moving average filter was used to reduce encoder noise, and an anti-windup clamp was added to prevent the integral term from growing too large during large errors or disturbances.

Through structured manual tuning, the final PID gain values were selected as:

Kp = 0.5, Ki = 1.7, Kd = 0.01

With these final values, the system achieved strong performance and successfully satisfied the assignment requirements.

Performance Metric | Final Result | Requirement | Status
Settling Time | 1.82 s | Minimum possible | Excellent
Maximum Overshoot | 0.8% | Less than 15% | Passed
Steady-State Error | 0.0% | Less than 2% | Passed

The final controller produced a fast, accurate, and stable motor response. The motor reached the target speed quickly, did not show sustained oscillations, and maintained almost zero steady-state error. This shows that the selected PID gains were suitable for the motor and hardware setup.

The robustness tests further proved that the system could handle real-world changes. During the manual load disturbance test, the motor speed dropped when the shaft was physically loaded, but the controller was able to recover and bring the speed back to the target value. The voltage variation test also showed that the integral action helped the system maintain accuracy even when the supply voltage changed.

One of the most important lessons from this project was understanding the difference between ideal theory and real hardware behaviour. In theory, a motor model may look smooth and predictable. However, in real implementation, several practical issues appear, such as encoder quantization noise,

CPU timing jitter, motor saturation, voltage limitations, and mechanical friction. Solving these issues through filtering, anti-windup protection, safe PCB design, and careful PID tuning was a major part of the project.

Overall, the completed system is stable, accurate, and reliable. It demonstrates how a Raspberry Pi can be used with encoder feedback and PID control to create a practical closed-loop motor speed control system. Therefore, this design is suitable for small automation applications such as conveyor belts, robotic mechanisms, and speed-controlled motor systems.

References
1. Raspberry Pi Ltd., “Raspberry Pi 4 Model B Datasheet,” Raspberry Pi Ltd., 2024. [Online]. Available: https://pip.raspberrypi.com/documents/RP-008341-DS-raspberry-pi-4-datasheet.pdf. [Accessed: May 1, 2026].
2. Raspberry Pi Ltd., “Raspberry Pi 4 Model B Specifications,” Raspberry Pi. [Online]. Available: https://www.raspberrypi.com/products/raspberry-pi-4-model-b/specifications/. [Accessed: May 1, 2026].
3. Handson Technology, “G12-N20 Geared Mini DC Motor Datasheet,” Handson Technology. [Online]. Available: https://www.handsontec.com/dataspecs/motor_fan/GA12-N20.pdf. [Accessed: May 1, 2026].
4. J. A. Bennett, “pigpio Library,” abyz.me.uk. [Online]. Available: https://abyz.me.uk/rpi/pigpio/. [Accessed: May 1, 2026].
5. Matplotlib Development Team, “Matplotlib Documentation,” Matplotlib. [Online]. Available: https://matplotlib.org/stable/index.html. [Accessed: May 1, 2026].
6. EasyEDA, “Generate Fabrication File Gerber,” EasyEDA Documentation. [Online]. Available: https://docs.easyeda.com/en/PCB/Gerber-Generate/. [Accessed: May 1, 2026].
7. N. S. Nise, Control Systems Engineering, 8th ed. Hoboken, NJ, USA: Wiley, 2019.

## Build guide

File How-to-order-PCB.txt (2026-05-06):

How to Order PCB

Please refer to:
https://prodocs.easyeda.com/en/pcb/order-order-pcb/index.html

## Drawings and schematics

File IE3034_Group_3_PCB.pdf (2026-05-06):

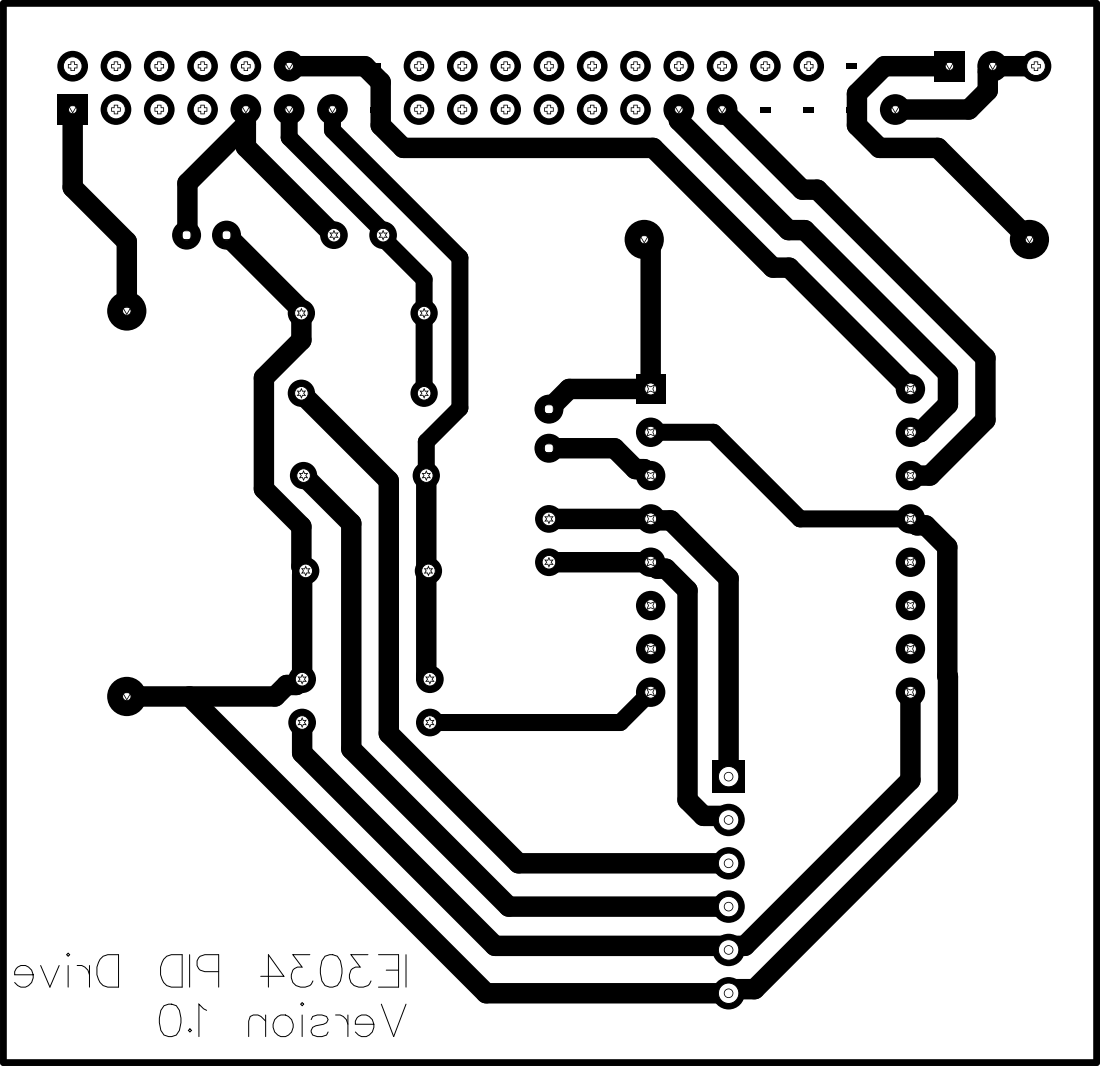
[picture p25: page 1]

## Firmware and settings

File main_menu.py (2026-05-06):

import pigpio
import time
import csv
import sys

# --- PINS (Custom PCB) ---
PWMA = 18; AIN1 = 6; AIN2 = 5
ENC_A = 27; ENC_B = 17  

# --- SETTINGS & TUNING ---
PPR = 350.0       

# FINAL OPTIMAL GAINS (PI Controller)
KP = 0.5
KI = 1.7
KD = 0.01

# --- SETUP ---
pi = pigpio.pi()
if not pi.connected: 
    print("Error: Run 'sudo pigpiod' first.")
    sys.exit()

for pin in [PWMA, AIN1, AIN2]: pi.set_mode(pin, pigpio.OUTPUT)
for pin in [ENC_A, ENC_B]: 
    pi.set_mode(pin, pigpio.INPUT)
    pi.set_pull_up_down(pin, pigpio.PUD_UP)

# --- ENCODER LOGIC ---
encoder_count = 0
def encoder_cb(gpio, level, tick):
    global encoder_count
    encoder_count += 1 
pi.callback(ENC_A, pigpio.RISING_EDGE, encoder_cb)

# --- MOTOR CONTROLLER ---
def set_motor(power):
    power = max(min(power, 100), -100) 
    if power > 0:   pi.write(AIN1, 1); pi.write(AIN2, 0)
    elif power < 0: pi.write(AIN1, 0); pi.write(AIN2, 1)
    else:           pi.write(AIN1, 0); pi.write(AIN2, 0)
    pi.set_PWM_dutycycle(PWMA, int(abs(power) * 2.55))
    
# --- THE AUTO-PLOTTER FUNCTION ---
def plot_results(filename, title):
    # LAZY IMPORT: Only loads the graph after the motor finishes!
    import matplotlib.pyplot as plt 
    
    print(f"\n>> Loading data and generating graph...")
    plt.close('all') 
    times, setpoints, rpms = [], [], []
    
    try:
        with open(filename, mode='r') as file:
            reader = csv.reader(file)
            next(reader) # Skip header
            for row in reader:
                times.append(float(row[0]))
                setpoints.append(float(row[1]))
                rpms.append(float(row[2]))
                
        if len(times) < 2:
            print(">> Error: Not enough data in CSV. The motor test may have failed.")
            return

        TARGET = setpoints[-1] if setpoints[-1] != 0 else 100.0
        upper_bound = TARGET * 1.02
        lower_bound = TARGET * 0.98

        # --- CALCULATE RUBRIC METRICS ---
        max_rpm = max(rpms)
        overshoot_pct = ((max_rpm - TARGET) / TARGET) * 100
        if overshoot_pct < 0: overshoot_pct = 0.0

        ss_rpm = sum(rpms[-10:]) / 10 if len(rpms) >= 10 else rpms[-1]
        ss_error_pct = (abs(TARGET - ss_rpm) / TARGET) * 100

        settling_time = None
        for i in range(len(rpms)-1, -1, -1):
            if rpms[i] > upper_bound or rpms[i] < lower_bound:
                if i < len(times) - 1:
                    settling_time = times[i+1]
                break
        if settling_time is None: settling_time = times[0]

        t_10 = next((times[i] for i, r in enumerate(rpms) if r >= TARGET * 0.1), None)
        t_90 = next((times[i] for i, r in enumerate(rpms) if r >= TARGET * 0.9), None)
        rise_time = (t_90 - t_10) if (t_90 is not None and t_10 is not None) else 0.0

        # --- CREATE THE PLOT ---
        plt.figure(figsize=(10, 6))
        plt.fill_between(times, lower_bound, upper_bound, color='gray', alpha=0.2, label='+/- 2% Settling Band')
        plt.plot(times, rpms, label='Motor Speed (RPM)', color='blue', linewidth=2)
        plt.axhline(y=TARGET, color='red', linestyle='--', label='Target (Setpoint)')

        stats_text = (
            f"--- Performance Metrics ---\n"
            f"Rise Time: {rise_time:.2f} s\n"
            f"Settling Time: {settling_time:.2f} s\n"
            f"Max Overshoot: {overshoot_pct:.1f}%\n"
            f"Steady-State Error: {ss_error_pct:.1f}%"
        )
        plt.text(0.95, 0.05, stats_text, transform=plt.gca().transAxes, fontsize=12,
                 verticalalignment='bottom', horizontalalignment='right',
                 bbox=dict(boxstyle='round', facecolor='white', alpha=0.9))

        plt.title(title, fontsize=14, fontweight='bold')
        plt.xlabel('Time (Seconds)', fontsize=12)
        plt.ylabel('Speed (RPM)', fontsize=12)
        plt.grid(True, linestyle='--', alpha=0.7)
        plt.legend(loc='upper right')

        image_name = filename.replace('.csv', '_plot.png')
        plt.savefig(image_name, dpi=300, bbox_inches='tight')
        
        print(f">> Graph opened! Close the graph window to return to the Main Menu.")
        plt.show()
        
    except Exception as e:
        print(f">> Critical Error generating plot: {e}")
        
    # --- THE CORE PID CONTROLLER FUNCTION ---
def run_motor_test(setpoint, duration, filename="test_data.csv"):
    global encoder_count
    integral = 0
    prev_error = 0
    encoder_count = 0 
    
    rpm_history = []
    FILTER_SIZE = 3  

    print(f"\n>> Starting Test: Target = {setpoint} RPM | Duration = {duration}s")
    print(">> Press Ctrl+C to stop early if needed.\n")

    try:
        with open(filename, mode='w', newline='') as file:
            writer = csv.writer(file)
            writer.writerow(["Time", "Setpoint", "RPM"])

            time.sleep(0.5) 
            start_time = time.time()
            last_time = start_time

            while True:
                time.sleep(0.1) 
                
                current_time = time.time()
                dt = current_time - last_time
                if dt <= 0: dt = 0.001 
                
                elapsed_time = current_time - start_time
                
                if elapsed_time >= duration:
                    print(f"\n>> Test completed successfully ({duration}s).")
                    break 
                
                raw_rpm = (encoder_count * 60.0) / (PPR * dt)
                encoder_count = 0 
                
                rpm_history.append(raw_rpm)
                if len(rpm_history) > FILTER_SIZE:
                    rpm_history.pop(0) 
                rpm = sum(rpm_history) / len(rpm_history) 
                
                error = setpoint - rpm
                integral = integral + (error * dt)
                integral = max(min(integral, 150), -150) 
                derivative = (error - prev_error) / dt
                
                output = (KP * error) + (KI * integral) + (KD * derivative)
                set_motor(output)
                
                writer.writerow([round(elapsed_time, 3), setpoint, round(rpm, 1)])
                print(f"Time: {elapsed_time:.1f}s | Target: {setpoint} | RPM: {rpm:5.1f}")
                
                prev_error = error
                last_time = current_time

    except KeyboardInterrupt:
        print("\n>> Test interrupted manually.")
    except Exception as e:
        print(f"\n>> CRITICAL MOTOR ERROR: {e}") 
    finally:
        set_motor(0) 
        print(f">> Motor stopped safely. Data saved to '{filename}'.")
        print(">> Preparing graph...")
        time.sleep(1)
        
# --- THE MENU INTERFACE ---
def main_menu():
    while True:
        print("\n" + "="*45)
        print("      DC MOTOR CONTROL SYSTEM - MAIN MENU")
        print("="*45)
        print("1. Run Standard PID Test (100 RPM, 10s) [Module 3]")
        print("2. Run Custom Target Speed Test         [Module 4]")
        print("3. Run Load Disturbance Test (15s)      [Module 4]")
        print("4. Exit System")
        print("="*45)
        
        choice = input("Select a test mode (1-4): ")
        
        if choice == '1':
            filename = "mod3_standard.csv"
            run_motor_test(setpoint=100.0, duration=10.0, filename=filename)
            plot_results(filename, "Module 3: Standard PID Step Response")
            
        elif choice == '2':
            try:
                speed = float(input("\nEnter Target RPM (e.g., 75, 125): "))
                filename = f"mod4_speed_{int(speed)}.csv"
                run_motor_test(setpoint=speed, duration=10.0, filename=filename)
                plot_results(filename, f"Module 4: Target Speed Test ({speed} RPM)")
            except ValueError:
                print("\nInvalid input. Please enter numbers only.")
                
        elif choice == '3':
            print("\nGet ready to manually pinch the motor shaft after 3 seconds!")
            filename = "mod4_disturbance.csv"
            run_motor_test(setpoint=100.0, duration=15.0, filename=filename)
            plot_results(filename, "Module 4: Load Disturbance Recovery")
            
        elif choice == '4':
            print("\nShutting down system. Goodbye!")
            set_motor(0)
            pi.stop()
            sys.exit()
            
        else:
            print("\nInvalid choice. Please select a number between 1 and 4.")

if __name__ == "__main__":
    main_menu()

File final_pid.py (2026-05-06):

import pigpio
import time
import csv

# --- PINS (Custom PCB) ---
PWMA = 18; AIN1 = 6; AIN2 = 5
ENC_A = 27; ENC_B = 17  

# --- SETTINGS & TUNING ---
SETPOINT = 100.0  
PPR = 350.0       

# TEST 1 GAINS (Initial Baseline)
KP = 0.5
KI = 1.0
KD = 0.0

# --- SETUP ---
pi = pigpio.pi()
if not pi.connected: exit("Error: Run 'sudo pigpiod'.")

for pin in [PWMA, AIN1, AIN2]: pi.set_mode(pin, pigpio.OUTPUT)
for pin in [ENC_A, ENC_B]: 
    pi.set_mode(pin, pigpio.INPUT)
    pi.set_pull_up_down(pin, pigpio.PUD_UP)

# --- ENCODER LOGIC ---
encoder_count = 0
def encoder_cb(gpio, level, tick):
    global encoder_count
    encoder_count += 1 
pi.callback(ENC_A, pigpio.RISING_EDGE, encoder_cb)

# --- MOTOR CONTROLLER ---
def set_motor(power):
    power = max(min(power, 100), -100) 
    if power > 0:   pi.write(AIN1, 1); pi.write(AIN2, 0)
    elif power < 0: pi.write(AIN1, 0); pi.write(AIN2, 1)
    else:           pi.write(AIN1, 0); pi.write(AIN2, 0)
    pi.set_PWM_dutycycle(PWMA, int(abs(power) * 2.55))

# --- MAIN PID LOOP WITH DATA LOGGING ---
integral = 0
prev_error = 0
start_time = time.time()
last_time = start_time

print(f"Running PID Test. Target: {SETPOINT} RPM")
print(f"Gains -> KP: {KP}, KI: {KI}, KD: {KD}")
print("Press Ctrl+C to stop after 6 seconds...")

with open('motor_data.csv', mode='w', newline='') as file:
    writer = csv.writer(file)
    writer.writerow(["Time", "Setpoint", "RPM"])

    try:
        while True:
            time.sleep(0.1) # 10 Hz loop
            
            current_time = time.time()
            dt = current_time - last_time
            elapsed_time = current_time - start_time
            
            # Read Sensor
            rpm = (encoder_count * 60.0) / (PPR * dt)
            encoder_count = 0 
            
            # Calculate Errors
            error = SETPOINT - rpm
            integral = integral + (error * dt)
            integral = max(min(integral, 150), -150) # Anti-windup
            derivative = (error - prev_error) / dt
            
            # Apply PID
            output = (KP * error) + (KI * integral) + (KD * derivative)
            set_motor(output)
            
            # Save Data
            writer.writerow([round(elapsed_time, 3), SETPOINT, round(rpm, 1)])
            print(f"Time: {elapsed_time:.1f}s | RPM: {rpm:5.1f} | Error: {error:5.1f}")
            
            prev_error = error
            last_time = current_time

    except KeyboardInterrupt:
        print("\nStopping motor...")
        set_motor(0) 
        pi.stop()
        print("Data saved to motor_data.csv!")
